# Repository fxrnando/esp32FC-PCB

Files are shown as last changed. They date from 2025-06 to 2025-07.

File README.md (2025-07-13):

# ESP32FC - PCB for X Quadcopter Drones
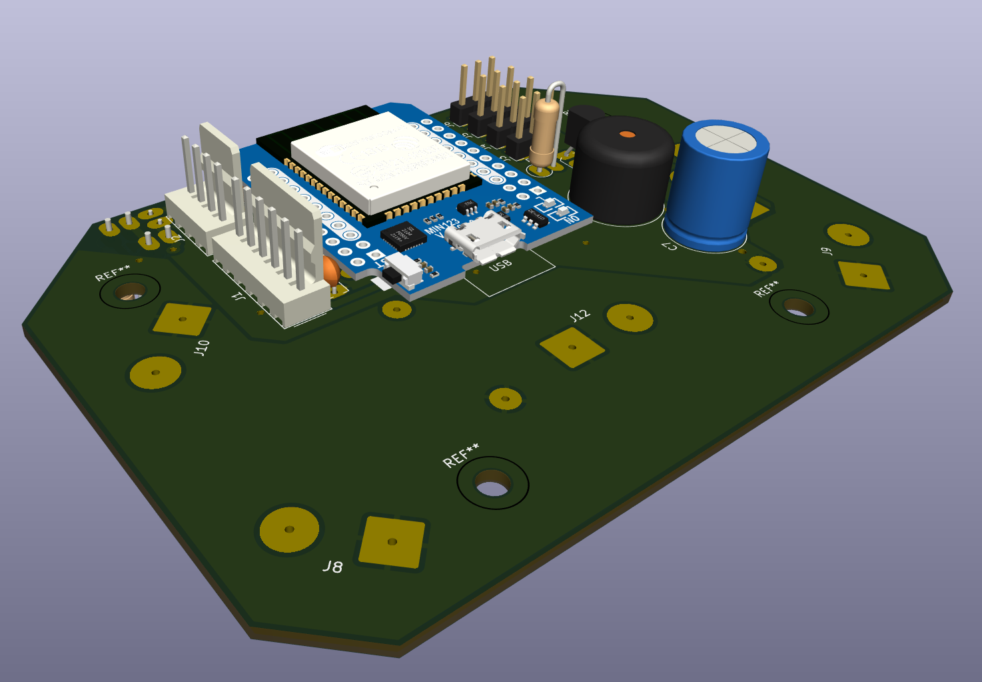
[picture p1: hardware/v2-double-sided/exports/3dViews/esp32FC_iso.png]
PCB v2 iso front view

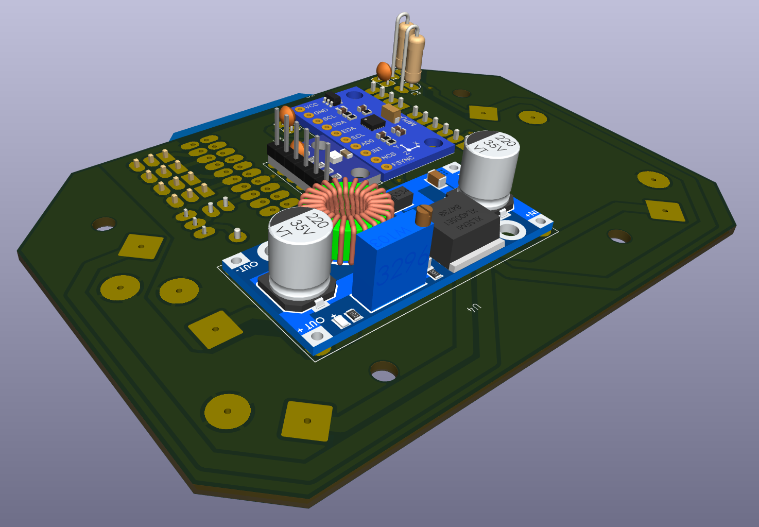
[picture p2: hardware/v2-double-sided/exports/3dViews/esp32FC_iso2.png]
PCB v2 iso back view


This repository contains the PCB designs and hardware documentation for a flight controller extension board based on the [esp-fc](https://github.com/rtlopez/esp-fc) project. The board is designed to connect an ESP32  microcontroller to a set of peripherals commonly used in unmanned aerial vehicles (UAVs) and robotics.

The project is intended to be developed using modular components commonly found in Arduino projects. This makes it easier for hobbyists to source and manipulate the parts, facilitating both assembly and PCB construction.

## 📦 Project Structure

The project contains two PCB versions:

* **v1-single-sided**: A one-layer PCB version, considered functional and stable, but not actively maintained.
**Note: This version has not yet been built or tested, as its dimensions are too large to fit inside the intended drone frame.**

* **v2-double-sided**: A two-layer PCB version, under active development, with continuous improvements and upgrades.

## 🧩 Features

* **Microcontroller**: ESP-WROOM-32 - ESP32 D1 Mini DevKit
* **IMU & Barometer**: SPI connection to MPU9250 and BMP250 (separated modules)
* **Motor Outputs**: 4 motor outputs, supporting PWM, Oneshot and DShot protocols
* **Serial Interfaces**:

  * `Serial1`: USB-to-serial for configuration (through Betaflight Configurator)
  * `Serial2`: Connection to ELRS receiver (CRSF protocol)
  * `Serial3`: Optional GPS or other peripheral like vtx smart audio (still not implemented in version 0.2.1)
* **Battery Monitoring**: Voltage divider for battery voltage measurement
* **Status Indication**: Piezo buzzer
* **Power Inputs**: LiPo battery connector
* **Power Outputs**:

  * ESCs power lines
  * Companion computer (e.g., Jetson Nano)

The board is designed to be installed in a standard F450 X-frame drone, but may also be adapted to fit other drone models with minor modifications.

## 📷 General Connections Diagram

Below is a visual representation of the wiring and placement of components for the quadcopter configuration using the ESP32FC board:

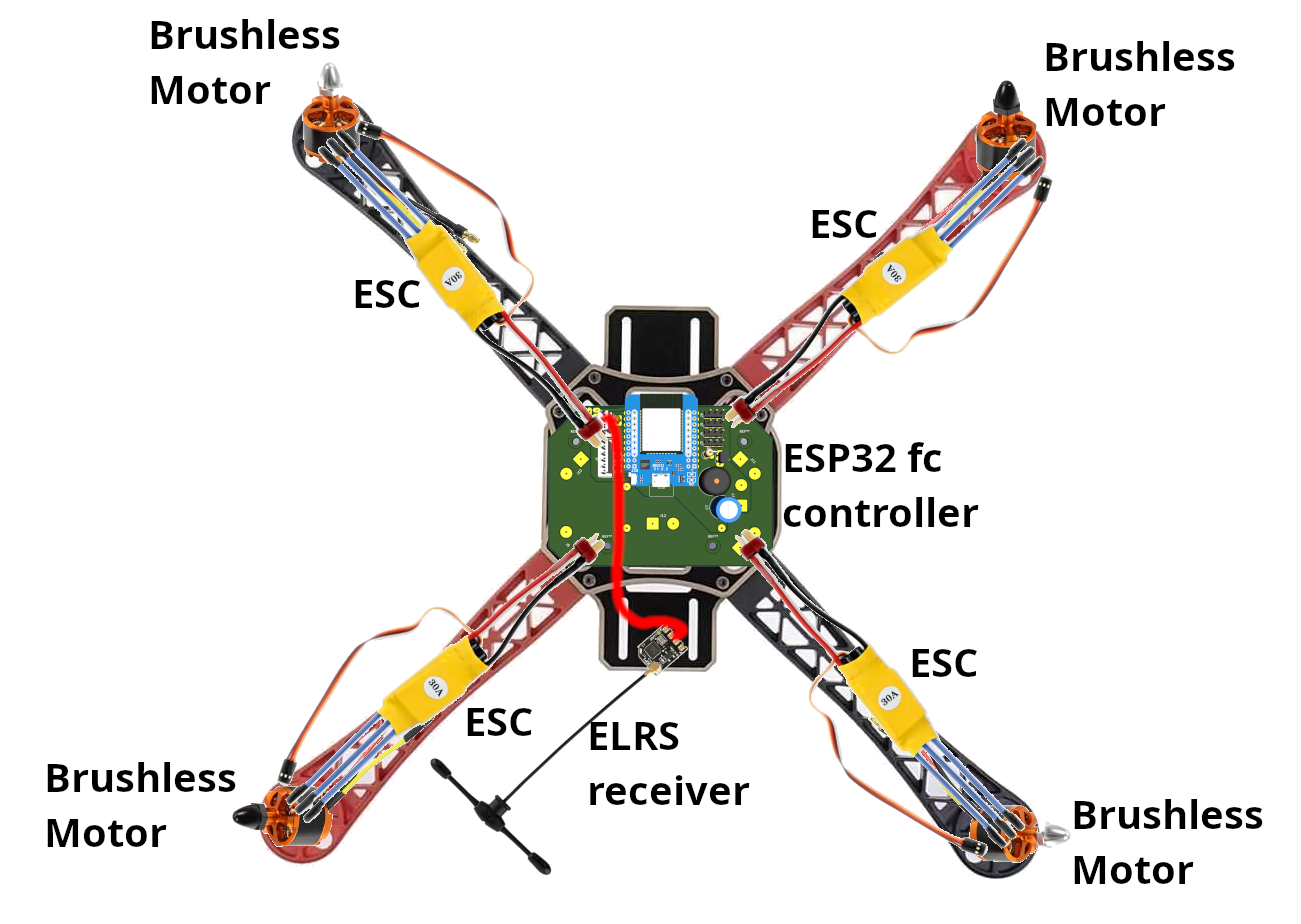
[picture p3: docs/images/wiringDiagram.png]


Legend:
* Yellow components: Electronic Speed Controllers (ESCs)
* Orange components: Brushless motors
* Center green board: ESP32FC custom PCB
* Black antenna: ELRS receiver module

All motor ESC signal wires are routed to the motor control pins on the PCB, while power and telemetry signals are handled via separate connections to the battery and optional modules.

## 🗂 Folder Overview

```text
hardware/                  PCB designs
  └── v1-single-sided/     Single-layer version
  └── v2-double-sided/     Dual-layer version
        └── exports/       3d images, BOM, g 
        └── kicad_pcb/    
  └── library/             Custom symbols & footprints
firmware/                  Optional test or support code
  └── ...
docs/                      Diagrams and usage docs and files
tools/                     Scripts for BOM or Gerber generation
```

## 🔧 Development

All initial configuration for the ESP32 module should be done following the instructions provided by @rtlopez in his esp-fc repository. This includes flashing the firmware, setting up the environment, and configuring the board.

Pin remapping specific to this board design (e.g., motor outputs, SPI, UARTs, battery monitor, buzzer) should be defined according to the layout described in the firmware/ section of this repository. Additional notes and configuration tips will be included there as development progresses.

All PCB designs are created using KiCad 9. Exports include Gerbers, BOMs, and 3D renders. Contributions are welcome, especially to the v2-double-sided version.

## 📝 License

This project is licensed under the **GPLv3**, following the upstream [esp-fc](https://github.com/rtlopez/esp-fc) licensing terms.

## 👤 Author & Maintainer

Developed and maintained by fxrnando. Based on the work of [@rtlopez](https://github.com/rtlopez).

---

Feel free to fork, modify, or contribute improvements to the hardware. If you build one, let us know!

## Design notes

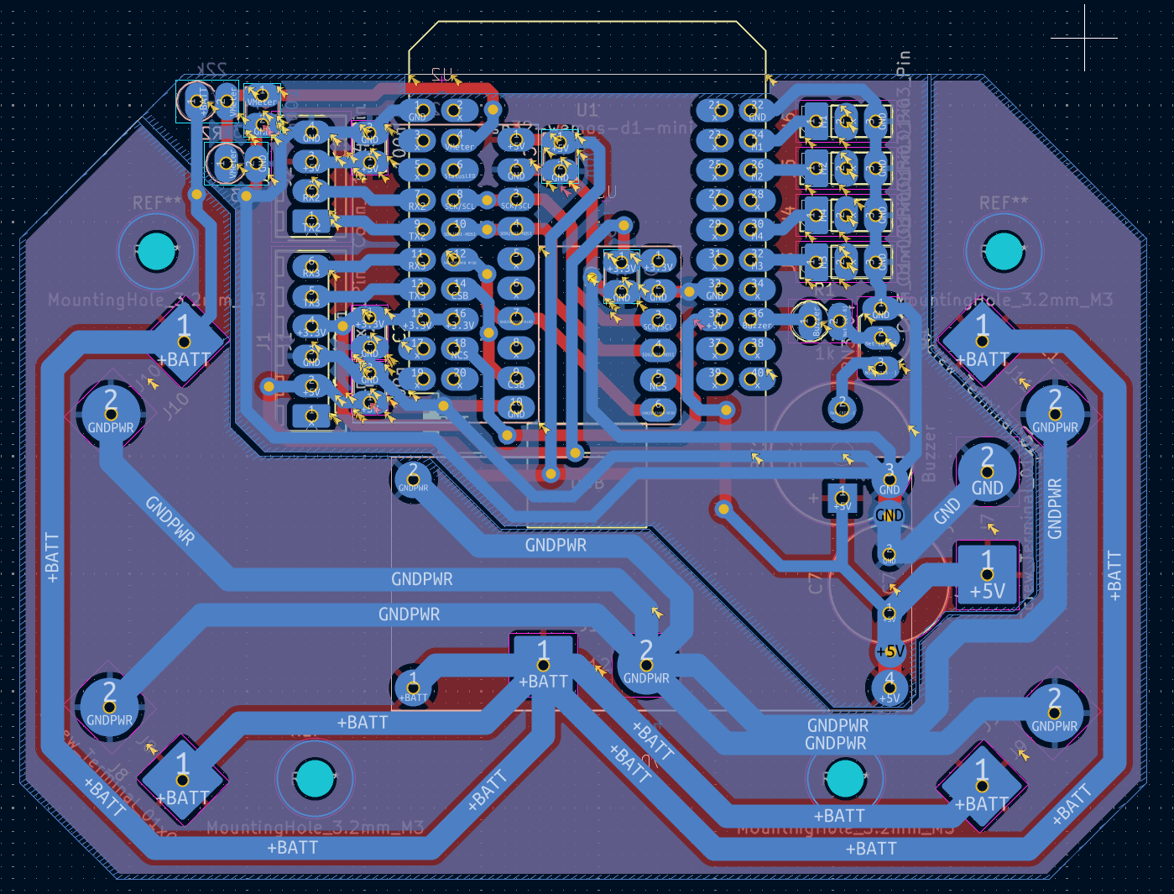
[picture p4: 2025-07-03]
hardware/v2-double-sided/exports/3dViews/cuBottom.png

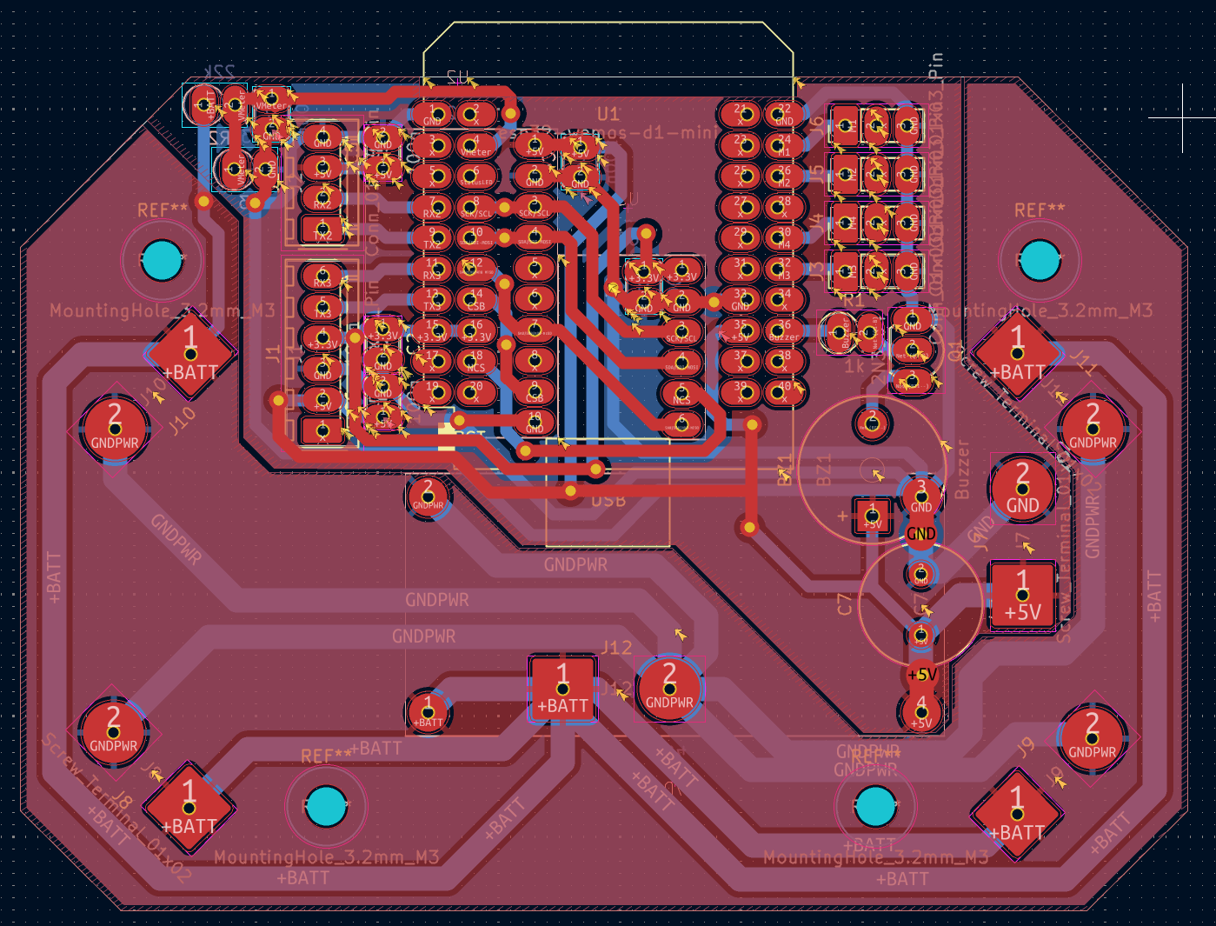
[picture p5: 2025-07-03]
hardware/v2-double-sided/exports/3dViews/cuTop.png

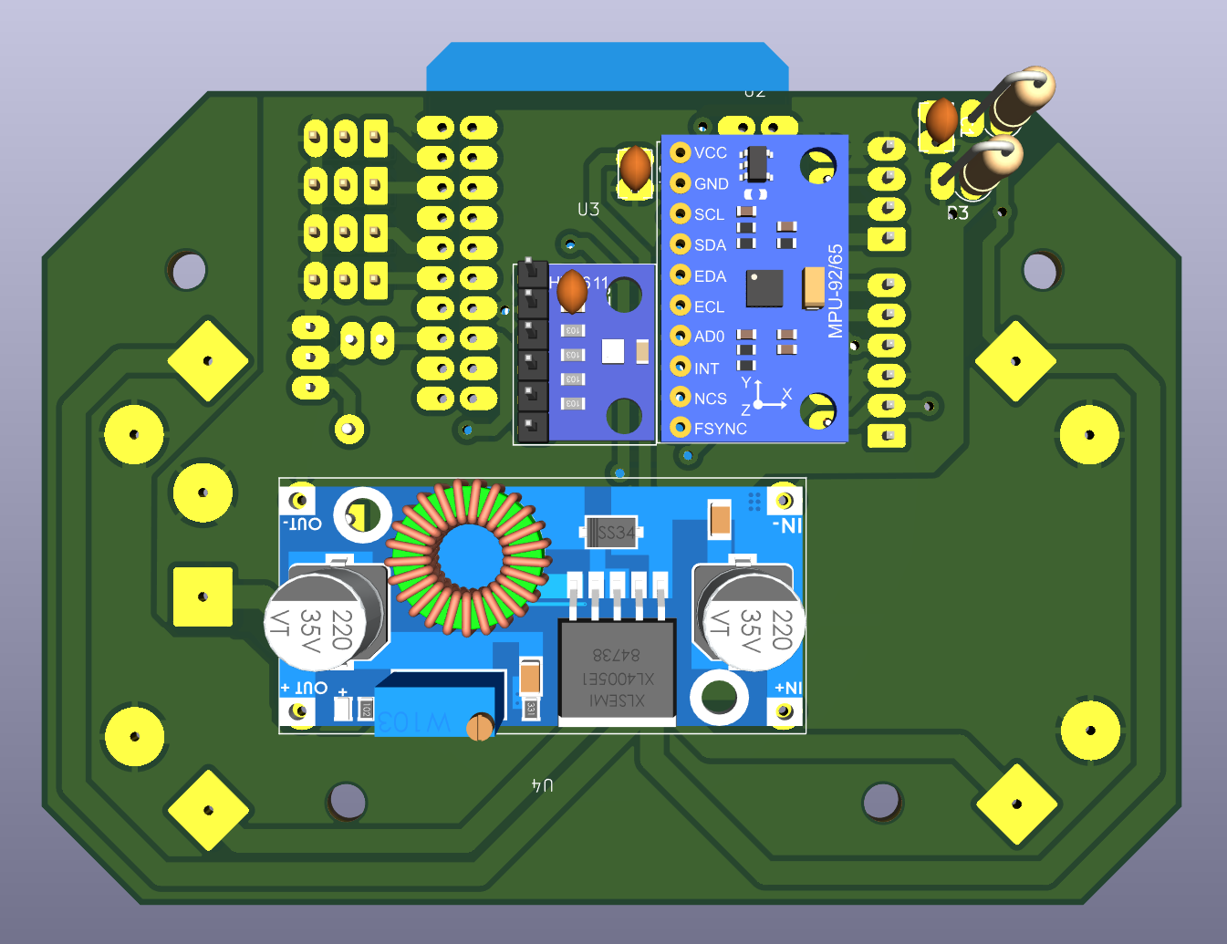
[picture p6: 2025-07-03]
hardware/v2-double-sided/exports/3dViews/esp32FC_back.png

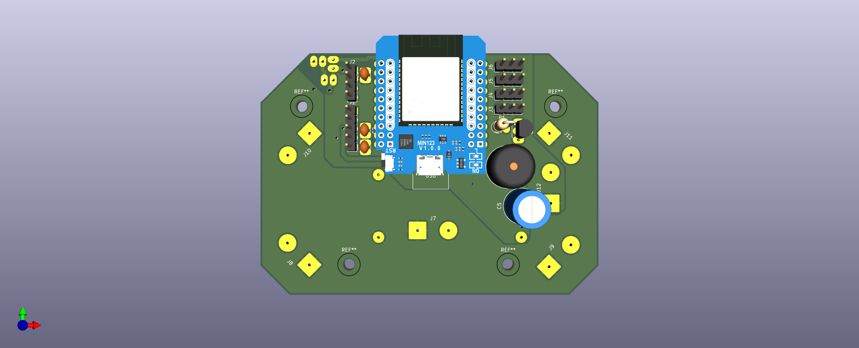
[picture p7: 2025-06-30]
hardware/v2-double-sided/exports/3dViews/esp32FC_front.png

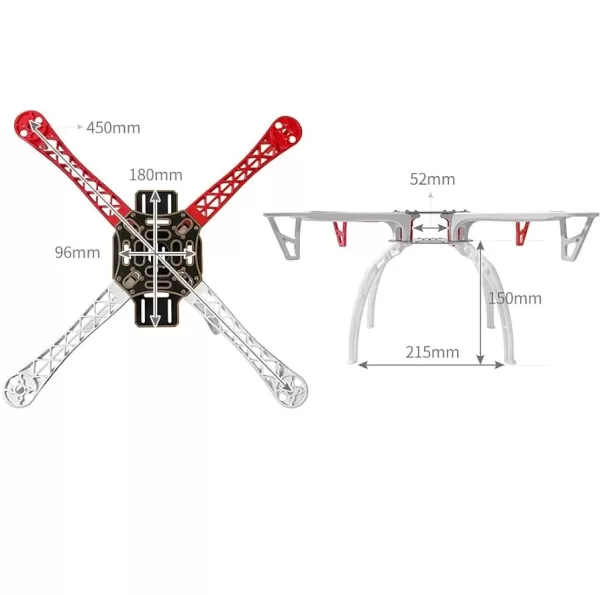
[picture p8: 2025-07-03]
docs/images/f450.webp

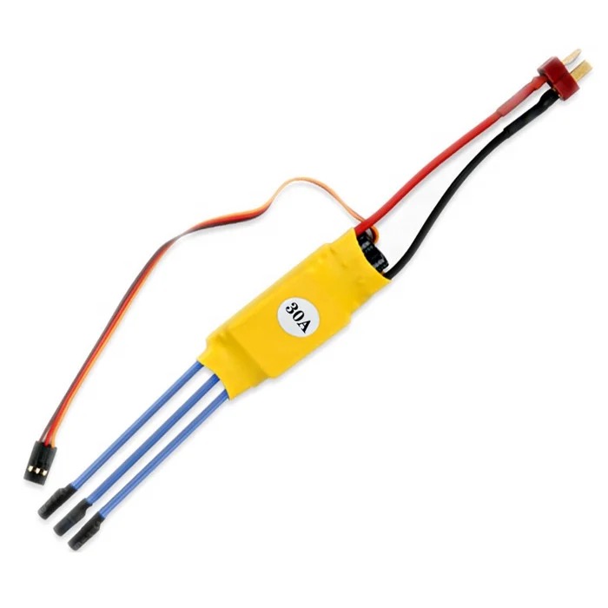
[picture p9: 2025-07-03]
docs/images/ESC.jpg

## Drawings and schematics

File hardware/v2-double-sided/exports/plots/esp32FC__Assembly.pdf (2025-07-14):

U4 Q1 | C3 U3 | R2 U2 | C1 C4 R3 | R1 1 | 2 | 3 | 4 | 5 | 6

A

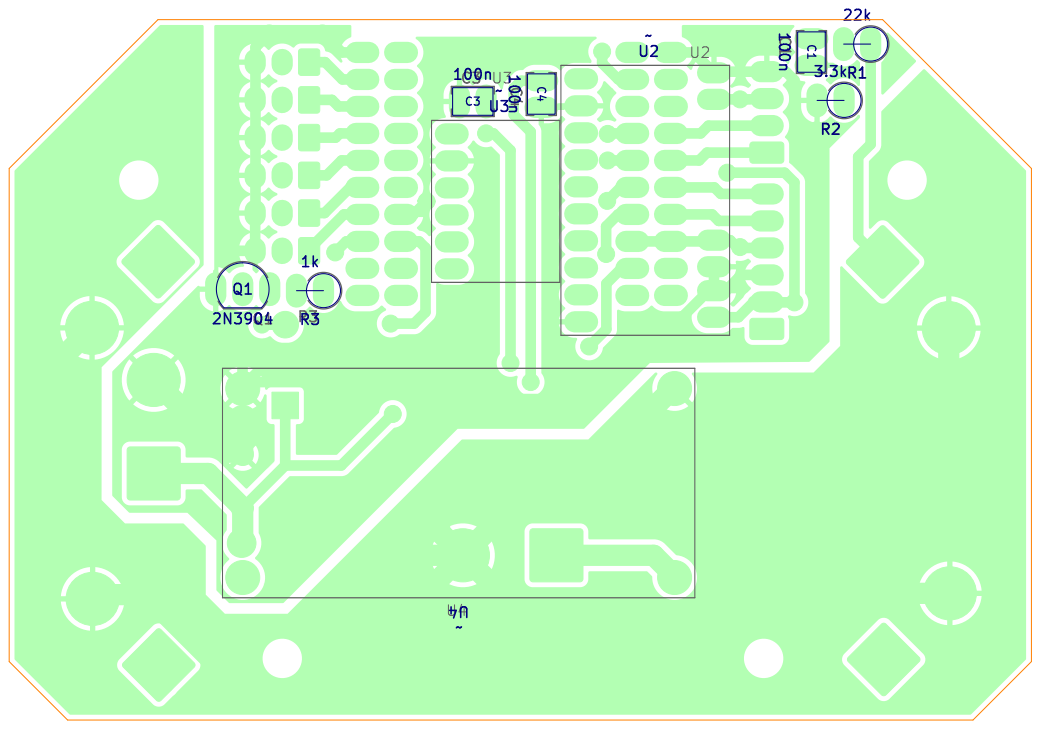
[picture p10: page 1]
D Date: 2025-06-29 KiCad; E.D.A. 9.0.3 Size: A4; Rev: v2.0; File: esp32FC.kicad_pcb Sheet: Colored; BOT Board2Pdf:; Colored; BOT -; Page

Id: /1 Title: ESP32FC - PCB for X Quadcopter Drones

1 | 2 | 3 | 4 | 5 | 6

A

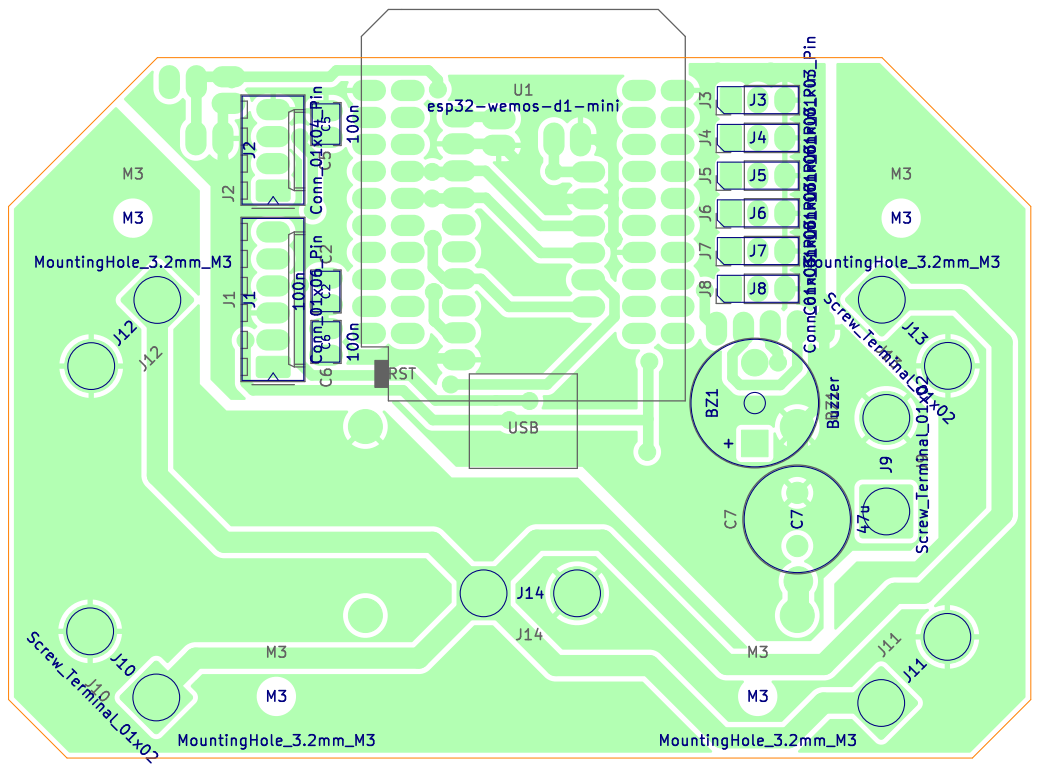
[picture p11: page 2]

Id: /1 Title: ESP32FC - PCB for X Quadcopter Drones

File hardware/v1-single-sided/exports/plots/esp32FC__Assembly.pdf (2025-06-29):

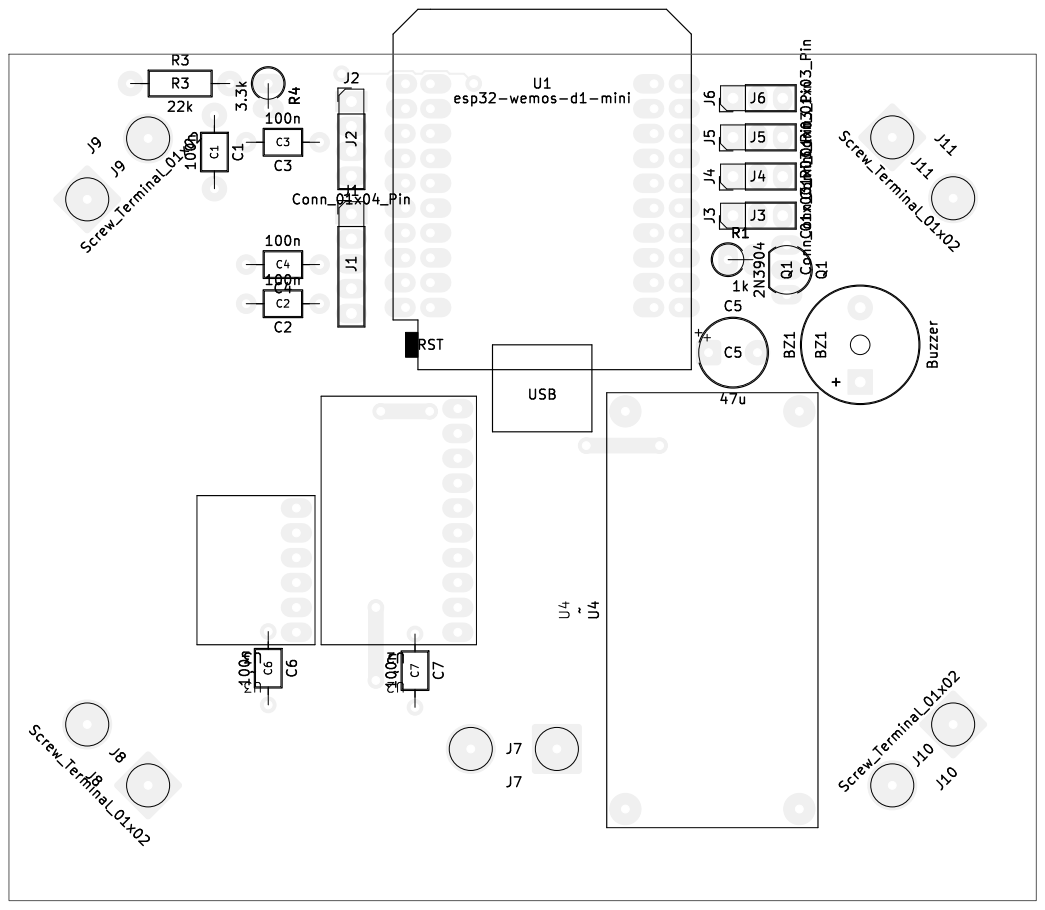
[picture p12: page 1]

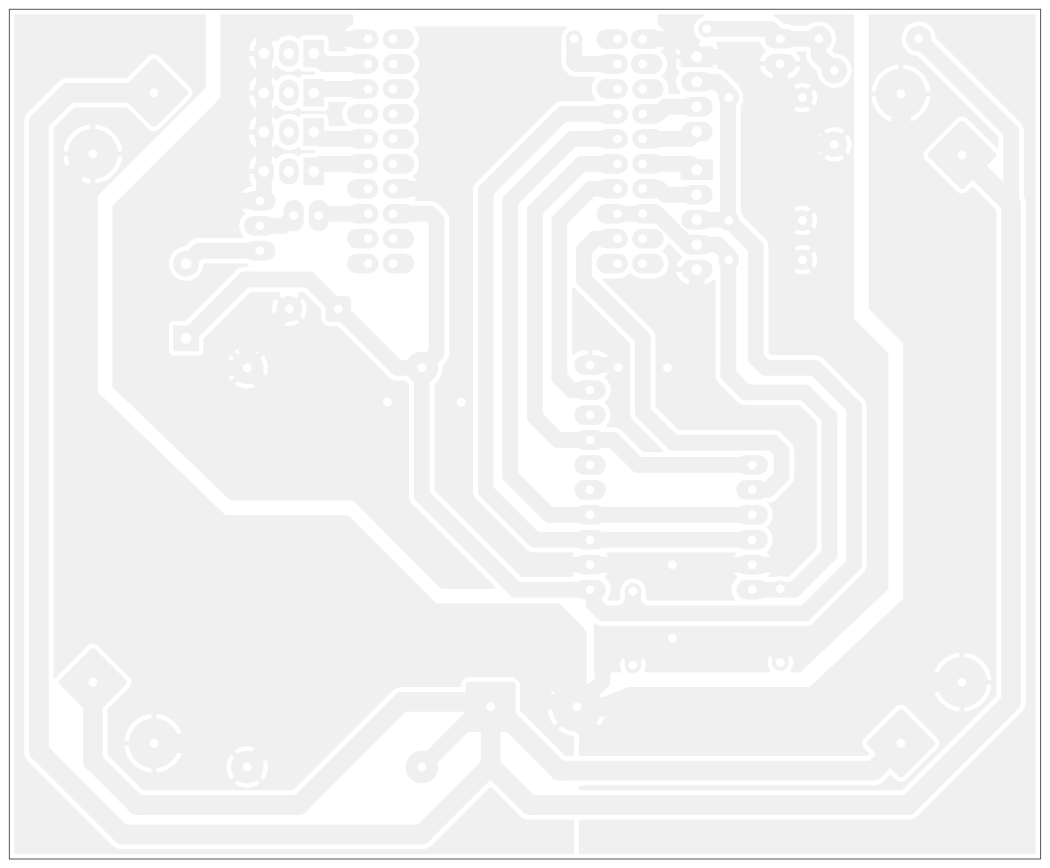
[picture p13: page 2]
D Date: KiCad; E.D.A. 9.0.2 Size: A4; Rev:; Id: /1 Title: File: esp32FC.kicad_pcb Sheet: Black; And; White; BOT Board2Pdf:; Black; BOT -; Page 2/2

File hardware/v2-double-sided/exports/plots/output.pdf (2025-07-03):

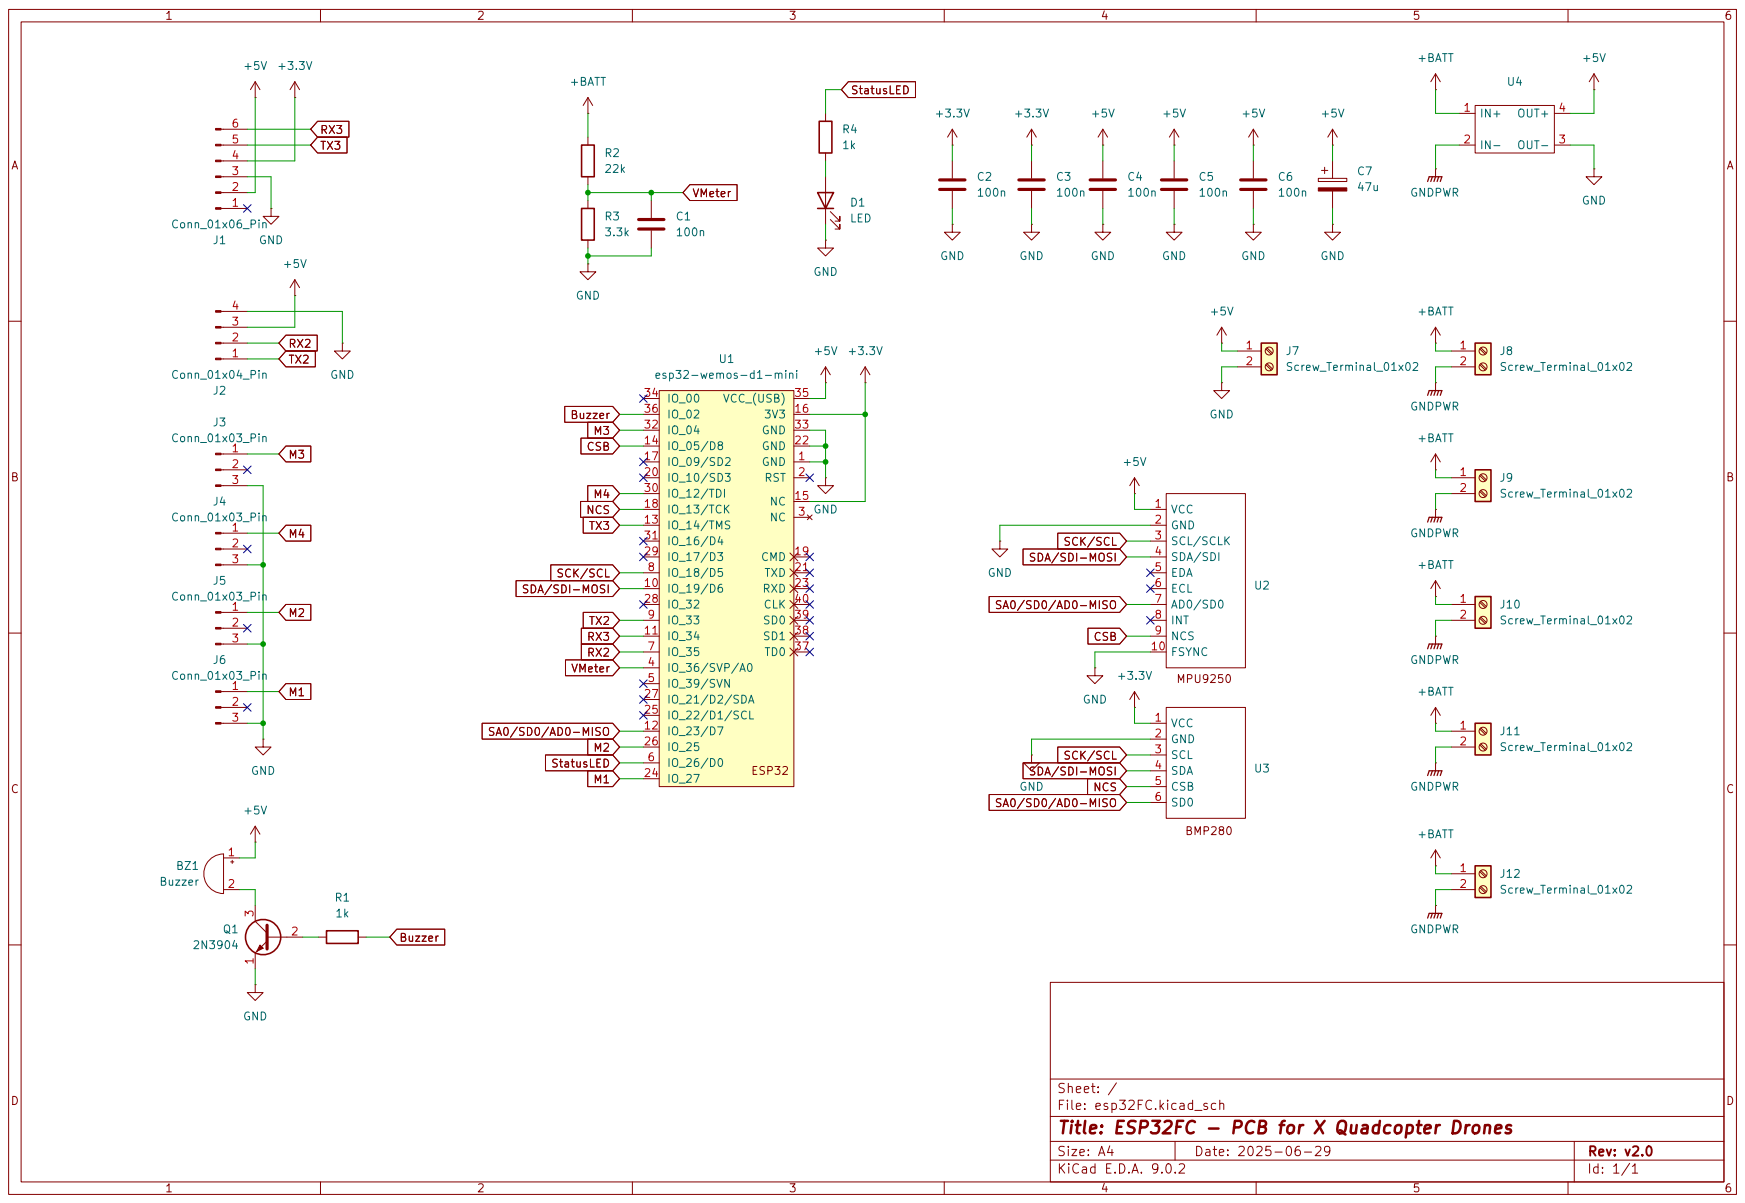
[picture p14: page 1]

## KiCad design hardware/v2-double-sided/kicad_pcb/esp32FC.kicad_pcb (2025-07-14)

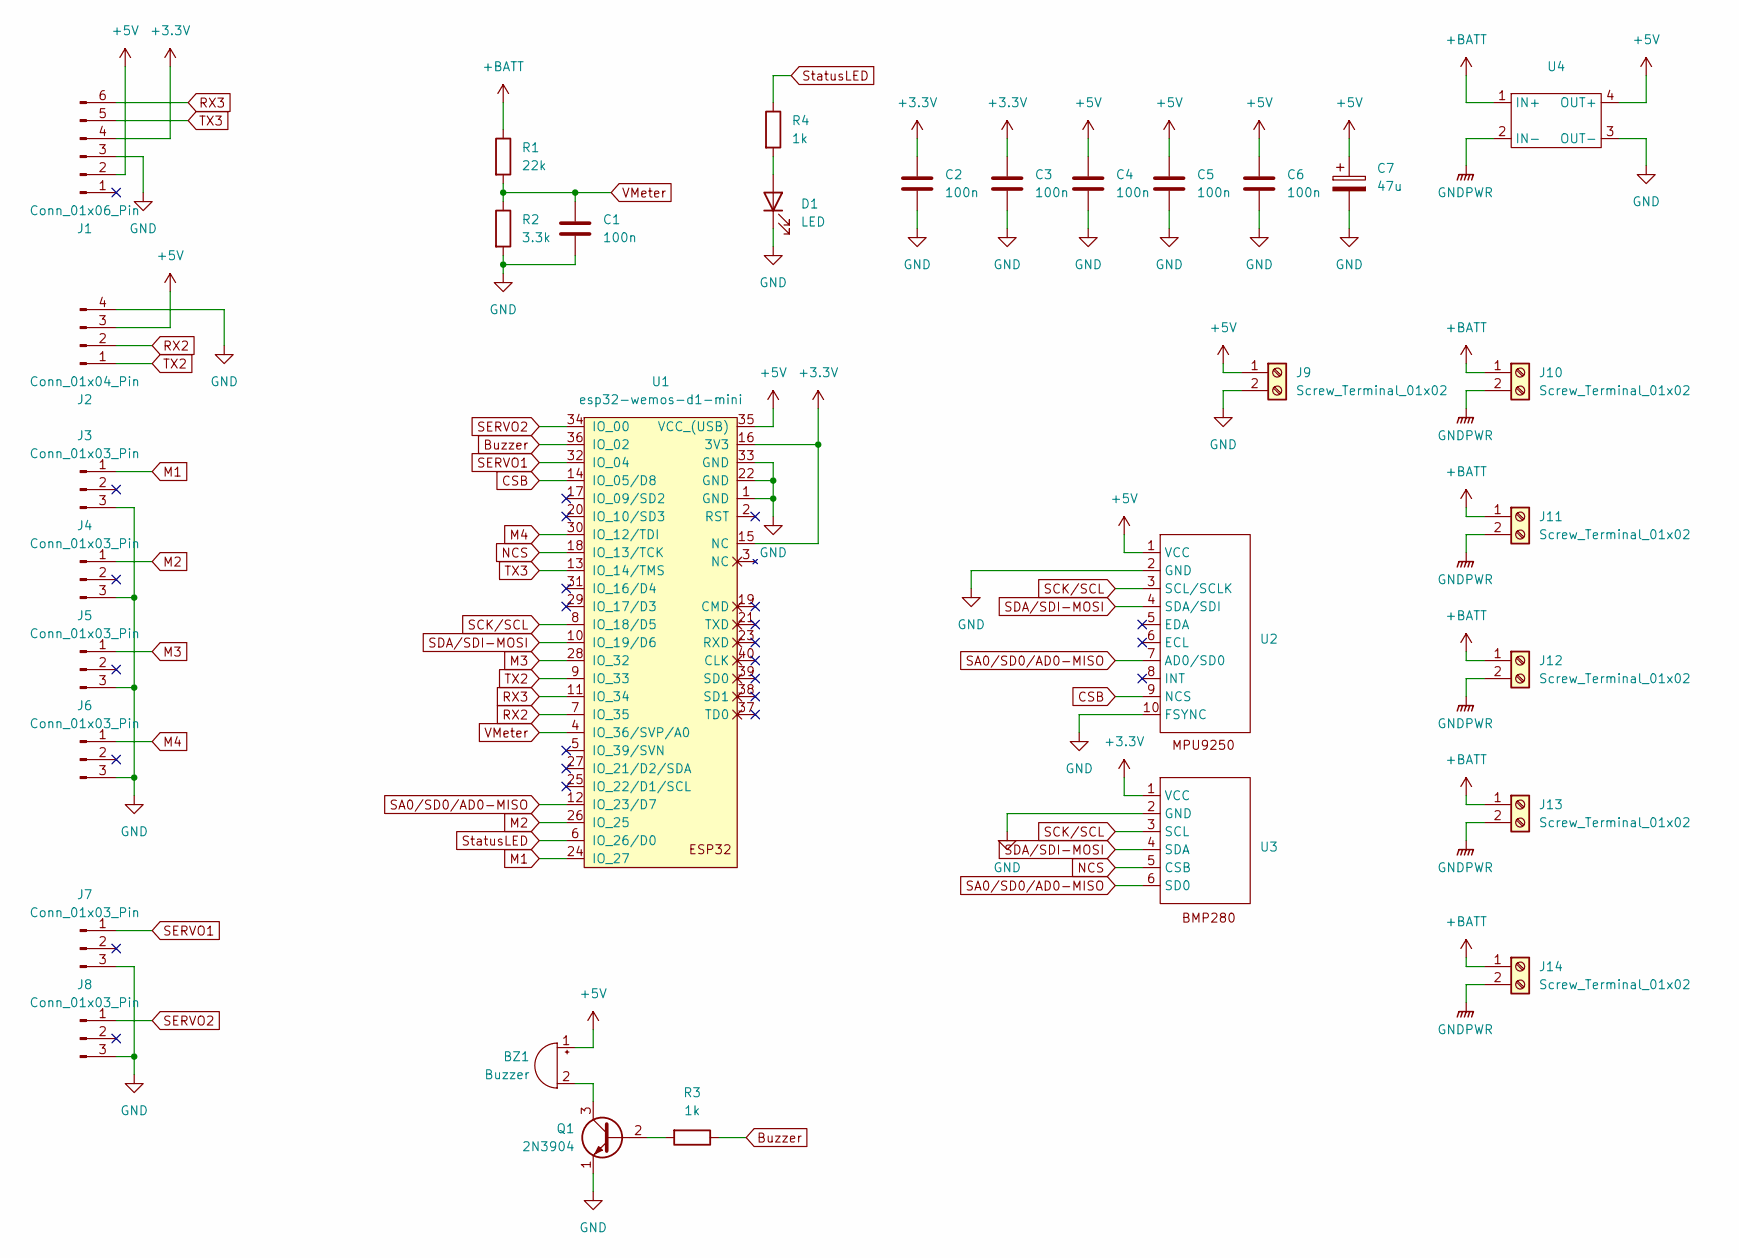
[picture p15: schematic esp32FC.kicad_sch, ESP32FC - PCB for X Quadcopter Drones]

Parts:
BZ1: Buzzer; Buzzer_12x9.5RM7.6
C1, C2, C3, C4, C5, C6: 100n; C_Disc_D3.8mm_W2.6mm_P2.50mm
C7: 47u; C_Radial_D10.0mm_H12.5mm_P5.00mm
D1: LED; LED_D3.0mm_Clear
J1: Conn_01x06_Pin; Molex_KK-254_AE-6410-06A_1x06_P2.54mm_Vertical
J2: Conn_01x04_Pin; Molex_KK-254_AE-6410-04A_1x04_P2.54mm_Vertical
J3, J4, J5, J6, J7, J8: Conn_01x03_Pin; PinHeader_1x03_P2.54mm_Vertical
J9, J10, J11, J12, J13, J14: Screw_Terminal_01x02; SolderWire-2.5sqmm_1x02_P8.8mm_D2.4mm_OD4.4mm
Q1: 2N3904; TO-92_Inline_Wide
R1: 22k; R_Axial_DIN0309_L9.0mm_D3.2mm_P2.54mm_Vertical
R2: 3.3k; R_Axial_DIN0309_L9.0mm_D3.2mm_P2.54mm_Vertical
R3: 1k; R_Axial_DIN0309_L9.0mm_D3.2mm_P2.54mm_Vertical
R4: 1k; R_Axial_DIN0207_L6.3mm_D2.5mm_P10.16mm_Horizontal
U1: esp32-wemos-d1-mini
U2: mpu9250
U3: bmp280
U4: xl4005 DC-DC stepdown module

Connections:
+3.3V: C2.1, C3.1, J1.4, U1.15 (NC), U1.16 (3V3), U3.1 (VCC)
+5V: BZ1.1 (+), C4.1, C5.1, C6.1, C7.1, J1.2, J2.3, J9.1, U1.35 (VCC_(USB)), U2.1 (VCC), U4.4 (OUT+)
+BATT: J10.1, J11.1, J12.1, J13.1, J14.1, R1.1, U4.1 (IN+)
Buzzer: R3.1, U1.36 (IO_02)
CSB: U1.14 (IO_05/D8), U2.9 (NCS)
GND: C1.2, C2.2, C3.2, C4.2, C5.2, C6.2, C7.2, D1.1 (K), J1.3, J2.4, J3.3, J4.3, J5.3, J6.3, J7.3, J8.3, J9.2, Q1.1 (E), R2.2, U1.1 (GND), U1.22 (GND), U1.33 (GND), U2.2 (GND), U2.10 (FSYNC), U3.2 (GND), U4.3 (OUT-)
GNDPWR: J10.2, J11.2, J12.2, J13.2, J14.2, U4.2 (IN-)
M1: J3.1, U1.24 (IO_27)
M2: J4.1, U1.26 (IO_25)
M3: J5.1, U1.28 (IO_32)
M4: J6.1, U1.30 (IO_12/TDI)
NCS: U1.18 (IO_13/TCK), U3.5 (CSB)
unnamed: BZ1.2 (-), Q1.3 (C)
unnamed: D1.2 (A), R4.2
unnamed: Q1.2 (B), R3.2
RX2: J2.2, U1.7 (IO_35)
RX3: J1.6, U1.11 (IO_34)
SA0/SD0/AD0-MISO: U1.12 (IO_23/D7), U2.7 (AD0/SD0), U3.6 (SD0)
SCK/SCL: U1.8 (IO_18/D5), U2.3 (SCL/SCLK), U3.3 (SCL)
SDA/SDI-MOSI: U1.10 (IO_19/D6), U2.4 (SDA/SDI), U3.4 (SDA)
SERVO1: J7.1, U1.32 (IO_04)
SERVO2: J8.1, U1.34 (IO_00)
StatusLED: R4.1, U1.6 (IO_26/D0)
TX2: J2.1, U1.9 (IO_33)
TX3: J1.5, U1.13 (IO_14/TMS)
VMeter: C1.1, R1.2, R2.1, U1.4 (IO_36/SVP/A0)

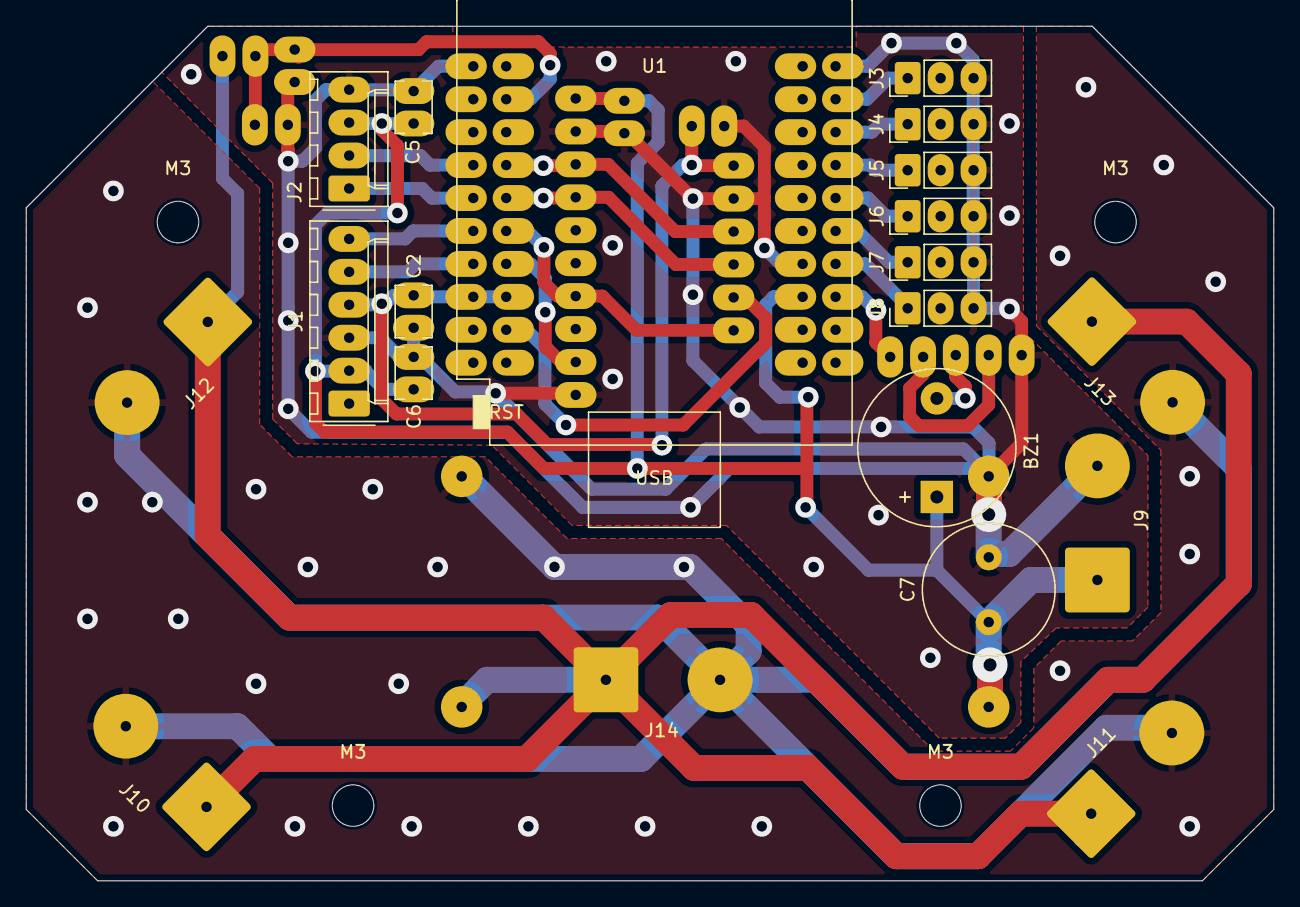
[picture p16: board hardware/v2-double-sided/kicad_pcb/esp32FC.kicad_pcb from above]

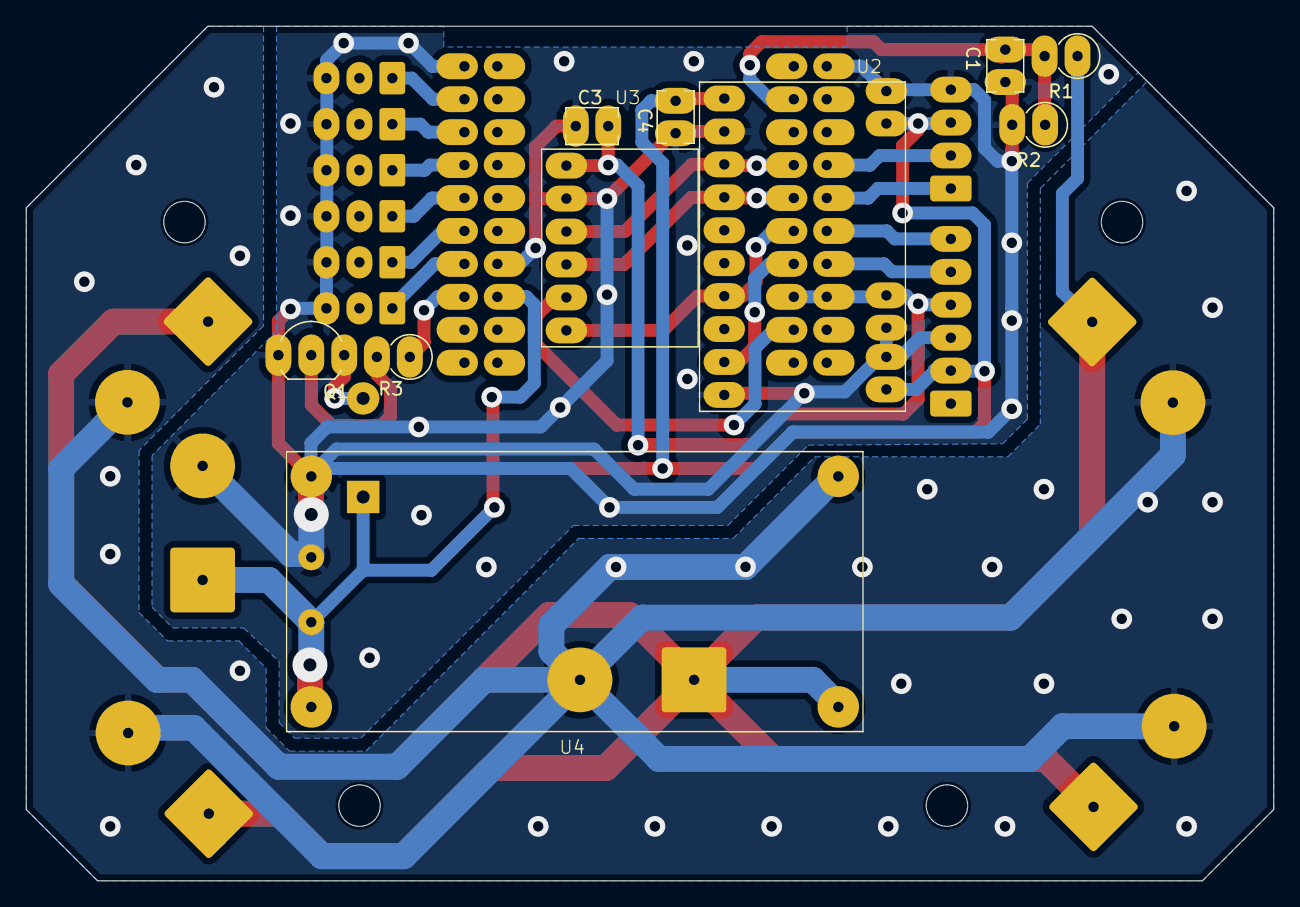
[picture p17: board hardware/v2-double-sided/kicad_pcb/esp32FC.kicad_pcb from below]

Board: 2 copper layers, 96.2 x 65.9 mm, 34 parts (10 on the bottom side), 24 nets.

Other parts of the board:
M3, M3#2, M3#3, M3#4: MountingHole_3.2mm_M3

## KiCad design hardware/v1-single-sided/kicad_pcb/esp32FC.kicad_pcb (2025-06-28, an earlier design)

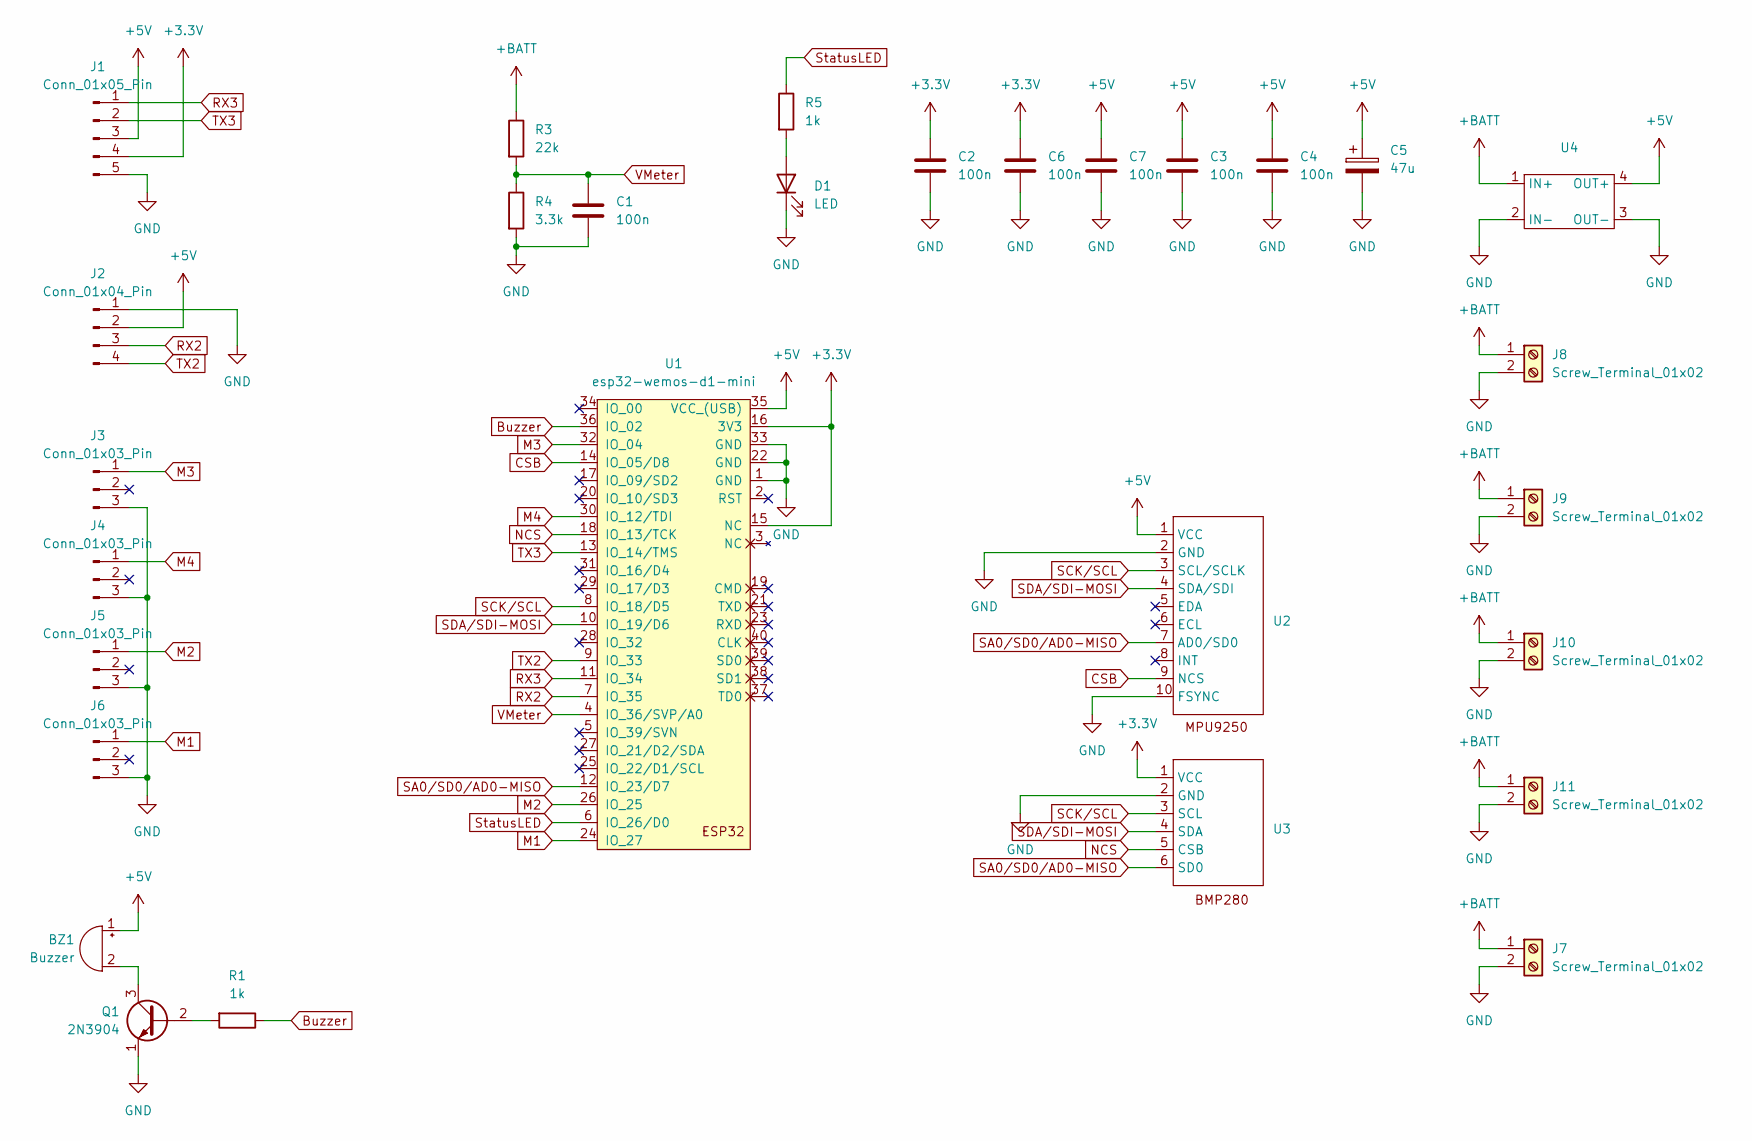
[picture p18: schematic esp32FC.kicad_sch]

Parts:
BZ1: Buzzer; Buzzer_12x9.5RM7.6
C1, C2, C3, C4, C6, C7: 100n; C_Axial_L3.8mm_D2.6mm_P7.50mm_Horizontal
C5: 47u; CP_Radial_Tantal_D7.0mm_P5.00mm
D1: LED; LED_D3.0mm_Clear
J1: Conn_01x05_Pin; PinHeader_1x05_P2.54mm_Vertical
J2: Conn_01x04_Pin; PinHeader_1x04_P2.54mm_Vertical
J3, J4, J5, J6: Conn_01x03_Pin; PinHeader_1x03_P2.54mm_Vertical
J7, J8, J9, J10, J11: Screw_Terminal_01x02; SolderWire-2.5sqmm_1x02_P8.8mm_D2.4mm_OD4.4mm
Q1: 2N3904; TO-92_Inline_Wide
R1: 1k; R_Axial_DIN0309_L9.0mm_D3.2mm_P2.54mm_Vertical
R3: 22k; R_Axial_DIN0207_L6.3mm_D2.5mm_P10.16mm_Horizontal
R4: 3.3k; R_Axial_DIN0309_L9.0mm_D3.2mm_P2.54mm_Vertical
R5: 1k; R_Axial_DIN0207_L6.3mm_D2.5mm_P10.16mm_Horizontal
U1: esp32-wemos-d1-mini
U2: mpu9250
U3: bmp280
U4: xl4005 DC-DC stepdown module

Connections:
+3.3V: C2.1, C6.1, J1.4, U1.15 (NC), U1.16 (3V3), U3.1 (VCC)
+5V: BZ1.1 (+), C3.1, C4.1, C5.1, C7.1, J1.3, J2.2, U1.35 (VCC_(USB)), U2.1 (VCC), U4.4 (OUT+)
+BATT: J7.1, J8.1, J9.1, J10.1, J11.1, R3.1, U4.1 (IN+)
Buzzer: R1.1, U1.36 (IO_02)
CSB: U1.14 (IO_05/D8), U2.9 (NCS)
GND: C1.2, C2.2, C3.2, C4.2, C5.2, C6.2, C7.2, D1.1 (K), J1.5, J2.1, J3.3, J4.3, J5.3, J6.3, J7.2, J8.2, J9.2, J10.2, J11.2, Q1.1 (E), R4.2, U1.1 (GND), U1.22 (GND), U1.33 (GND), U2.2 (GND), U2.10 (FSYNC), U3.2 (GND), U4.2 (IN-), U4.3 (OUT-)
M1: J6.1, U1.24 (IO_27)
M2: J5.1, U1.26 (IO_25)
M3: J3.1, U1.32 (IO_04)
M4: J4.1, U1.30 (IO_12/TDI)
NCS: U1.18 (IO_13/TCK), U3.5 (CSB)
unnamed: BZ1.2 (-), Q1.3 (C)
unnamed: D1.2 (A), R5.2
unnamed: Q1.2 (B), R1.2
RX2: J2.3, U1.7 (IO_35)
RX3: J1.1, U1.11 (IO_34)
SA0/SD0/AD0-MISO: U1.12 (IO_23/D7), U2.7 (AD0/SD0), U3.6 (SD0)
SCK/SCL: U1.8 (IO_18/D5), U2.3 (SCL/SCLK), U3.3 (SCL)
SDA/SDI-MOSI: U1.10 (IO_19/D6), U2.4 (SDA/SDI), U3.4 (SDA)
StatusLED: R5.1, U1.6 (IO_26/D0)
TX2: J2.4, U1.9 (IO_33)
TX3: J1.2, U1.13 (IO_14/TMS)
VMeter: C1.1, R3.2, R4.1, U1.4 (IO_36/SVP/A0)

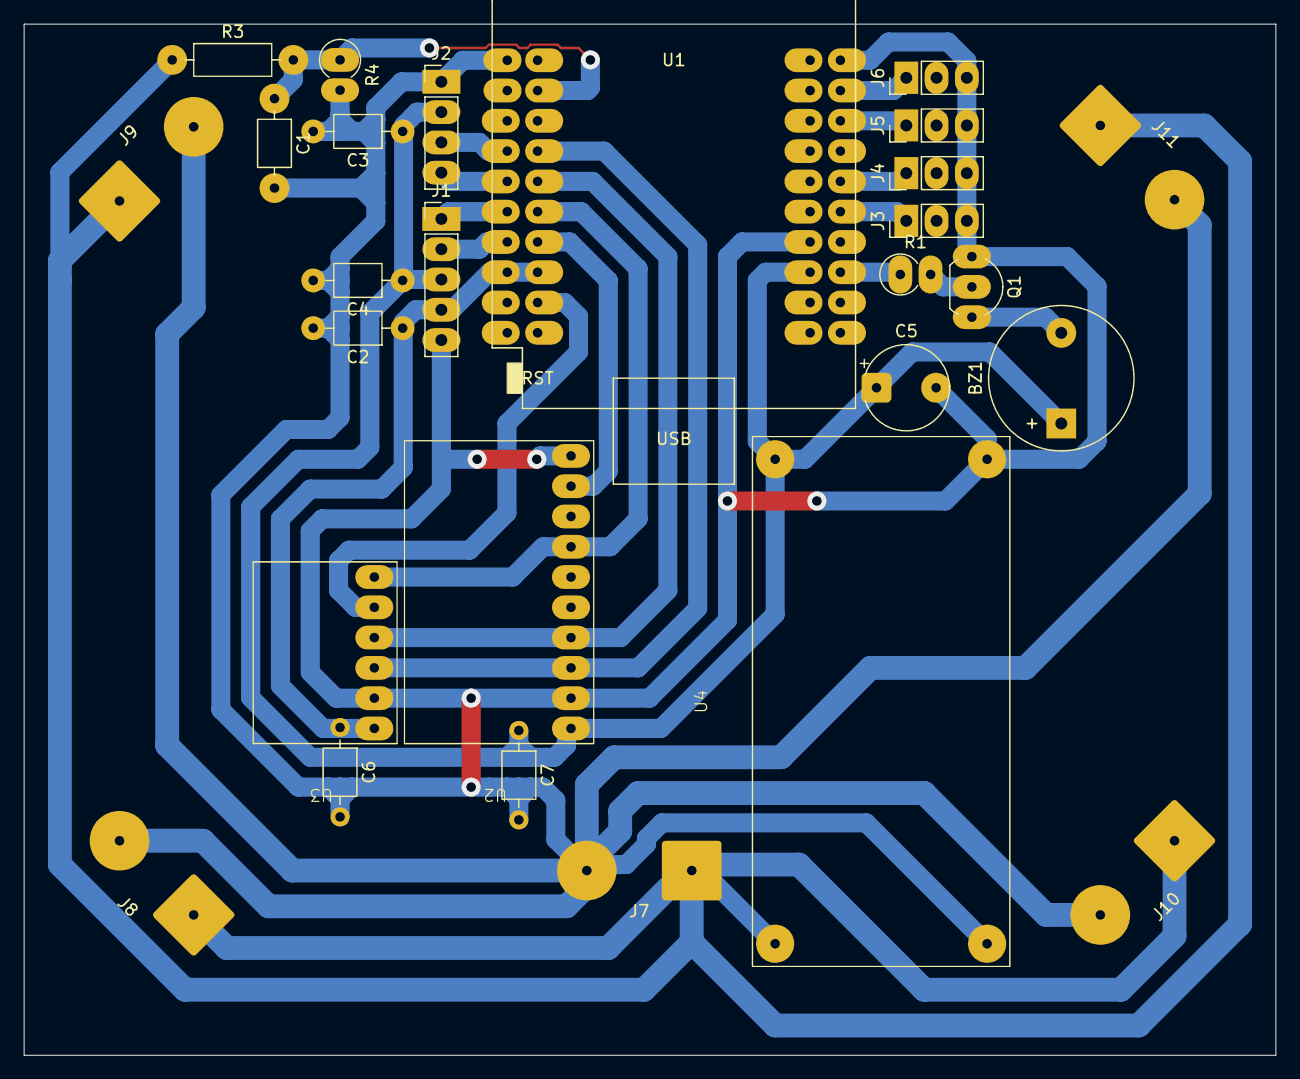
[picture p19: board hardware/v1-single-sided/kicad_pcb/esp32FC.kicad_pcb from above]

Board: 2 copper layers, 105.0 x 86.5 mm, 27 parts (0 on the bottom side), 21 nets.

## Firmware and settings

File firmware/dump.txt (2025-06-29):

Entering CLI Mode, type 'exit' to return, or 'help'
# ESPF ESP32 v0.2.1 120a1a6 Feb  4 2025 21:46:48 1.43 8.4.0 201103
# dump 
defaults
set features 1032
set debug_mode NONE
set debug_axis 1
set gyro_bus AUTO
set gyro_dev AUTO
set gyro_dlpf 256Hz
set gyro_align DEFAULT
set gyro_lpf_type PT1
set gyro_lpf_freq 100
set gyro_lpf2_type PT1
set gyro_lpf2_freq 213
set gyro_lpf3_type FO
set gyro_lpf3_freq 150
set gyro_notch1_freq 0
set gyro_notch1_cutoff 0
set gyro_notch2_freq 0
set gyro_notch2_cutoff 0
set gyro_dyn_lpf_min 170
set gyro_dyn_lpf_max 425
set gyro_dyn_notch_q 300
set gyro_dyn_notch_count 4
set gyro_dyn_notch_min 80
set gyro_dyn_notch_max 400
set gyro_rpm_harmonics 3
set gyro_rpm_q 500
set gyro_rpm_min_freq 100
set gyro_rpm_fade 30
set gyro_rpm_weight_1 100
set gyro_rpm_weight_2 100
set gyro_rpm_weight_3 100
set gyro_rpm_tlm_lpf_freq 150
set gyro_offset_x -25
set gyro_offset_y 13
set gyro_offset_z 1
set accel_bus AUTO
set accel_dev AUTO
set accel_lpf_type BIQUAD
set accel_lpf_freq 15
set accel_offset_x -7208
set accel_offset_y -4363
set accel_offset_z -1098
set mag_bus AUTO
set mag_dev AUTO
set mag_align DEFAULT
set mag_filter_type BIQUAD
set mag_filter_lpf 10
set mag_offset_x 0
set mag_offset_y 0
set mag_offset_z 0
set mag_scale_x 1000
set mag_scale_y 1000
set mag_scale_z 1000
set baro_bus AUTO
set baro_dev AUTO
set baro_lpf_type BIQUAD
set baro_lpf_freq 10
set board_align_roll 0
set board_align_pitch 0
set board_align_yaw 0
set vbat_source NONE
set vbat_scale 100
set vbat_mul 1
set vbat_div 10
set vbat_cell_warn 350
set ibat_source NONE
set ibat_scale 100
set ibat_offset 0
set fusion_mode MAHONY
set fusion_gain_p 50
set fusion_gain_i 5
set input_rate_type ACTUAL
set input_roll_rate 20
set input_roll_srate 40
set input_roll_expo 0
set input_roll_limit 1998
set input_pitch_rate 20
set input_pitch_srate 40
set input_pitch_expo 0
set input_pitch_limit 1998
set input_yaw_rate 30
set input_yaw_srate 36
set input_yaw_expo 0
set input_yaw_limit 1998
set input_deadband 3
set input_min 885
set input_mid 1500
set input_max 2115
set input_interpolation AUTO
set input_interpolation_interval 26
set input_filter_type FILTER
set input_lpf_type PT3
set input_lpf_freq 0
set input_lpf_factor 50
set input_ff_lpf_type PT3
set input_ff_lpf_freq 0
set input_rssi_channel 0
set input_0 0 1000 1500 2000 A 1500
set input_1 1 1000 1500 2000 A 1500
set input_2 3 1000 1500 2000 A 1500
set input_3 2 1000 1500 2000 A 1000
set input_4 4 1000 1500 2000 H 1500
set input_5 5 1000 1500 2000 H 1500
set input_6 6 1000 1500 2000 H 1500
set input_7 7 1000 1500 2000 H 1500
set input_8 8 1000 1500 2000 H 1500
set input_9 9 1000 1500 2000 H 1500
set input_10 10 1000 1500 2000 H 1500
set input_11 11 1000 1500 2000 H 1500
set input_12 12 1000 1500 2000 H 1500
set input_13 13 1000 1500 2000 H 1500
set input_14 14 1000 1500 2000 H 1500
set input_15 15 1000 1500 2000 H 1500
set failsafe_delay 4
set failsafe_kill_switch 0
set serial_0 1 115200 115200
set serial_1 65 115200 115200
set serial_2 64 115200 115200
set serial_soft_0 1 115200 0
set scaler_0 0 0 20 400
set scaler_1 0 0 20 400
set scaler_2 0 0 20 200
set mode_0 0 4 1700 2100 0 0
set mode_1 1 5 1300 1700 0 0
set mode_2 3 9 1700 2100 0 0
set mode_3 0 4 900 900 0 0
set mode_4 0 4 900 900 0 0
set mode_5 0 4 900 900 0 0
set mode_6 0 4 900 900 0 0
set mode_7 0 4 900 900 0 0
set pid_sync 3
set pid_roll_p 42
set pid_roll_i 85
set pid_roll_d 24
set pid_roll_f 72
set pid_pitch_p 46
set pid_pitch_i 90
set pid_pitch_d 26
set pid_pitch_f 76
set pid_yaw_p 45
set pid_yaw_i 90
set pid_yaw_d 0
set pid_yaw_f 72
set pid_level_p 45
set pid_level_i 0
set pid_level_d 0
set pid_level_angle_limit 55
set pid_level_rate_limit 300
set pid_level_lpf_type PT1
set pid_level_lpf_freq 90
set pid_yaw_lpf_type PT1
set pid_yaw_lpf_freq 90
set pid_dterm_lpf_type PT1
set pid_dterm_lpf_freq 128
set pid_dterm_lpf2_type PT1
set pid_dterm_lpf2_freq 128
set pid_dterm_notch_freq 0
set pid_dterm_notch_cutoff 0
set pid_dterm_dyn_lpf_min 60
set pid_dterm_dyn_lpf_max 145
set pid_dterm_weight 30
set pid_iterm_limit 30
set pid_iterm_zero 1
set pid_iterm_relax RP
set pid_iterm_relax_cutoff 15
set pid_tpa_scale 10
set pid_tpa_breakpoint 1650
set mixer_sync 1
set mixer_type QUADX
set mixer_yaw_reverse 1
set mixer_throttle_limit_type NONE
set mixer_throttle_limit_percent 100
set mixer_output_limit 100
set output_motor_protocol PWM
set output_motor_async 1
set output_motor_rate 60
set output_motor_poles 14
set output_servo_rate 0
set output_min_command 1000
set output_min_throttle 1070
set output_max_throttle 1940
set output_dshot_idle 550
set output_dshot_telemetry 0
set output_0 M N 1000 1500 2000
set output_1 M N 1000 1500 2000
set output_2 M N 1000 1500 2000
set output_3 M N 1000 1500 2000
set output_4 M N 1000 1500 2000
set output_5 M N 1000 1500 2000
set output_6 M N 1000 1500 2000
set output_7 M N 1000 1500 2000
set pin_input_rx 32
set pin_output_0 27
set pin_output_1 25
set pin_output_2 4
set pin_output_3 12
set pin_output_4 -1
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

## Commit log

2025-06-28 Added first PCB version (1 sided one).
    [esp32FC.kicad_pcb, esp32FC.kicad_sch]
2025-06-29 Updated readme and added exports for v1 PCB
    [dump.txt]
2025-06-29 Created v2 PCB
    [esp32FC.kicad_pcb, esp32FC.kicad_sch]
2025-06-30 Added screw holes and export files
    [esp32FC.kicad_pcb, esp32FC.kicad_sch]
2025-07-01 Modified connectors for serial connections, now used molex connectors
    [esp32FC.kicad_pcb, esp32FC.kicad_sch]
2025-07-13 Modified the PCB so it now has two ground layers instead of one power and one ground.
    [esp32FC.kicad_pcb]
2025-07-14 Added two additional outs, to connect two additional servos
    [esp32FC.kicad_pcb, esp32FC.kicad_sch]
